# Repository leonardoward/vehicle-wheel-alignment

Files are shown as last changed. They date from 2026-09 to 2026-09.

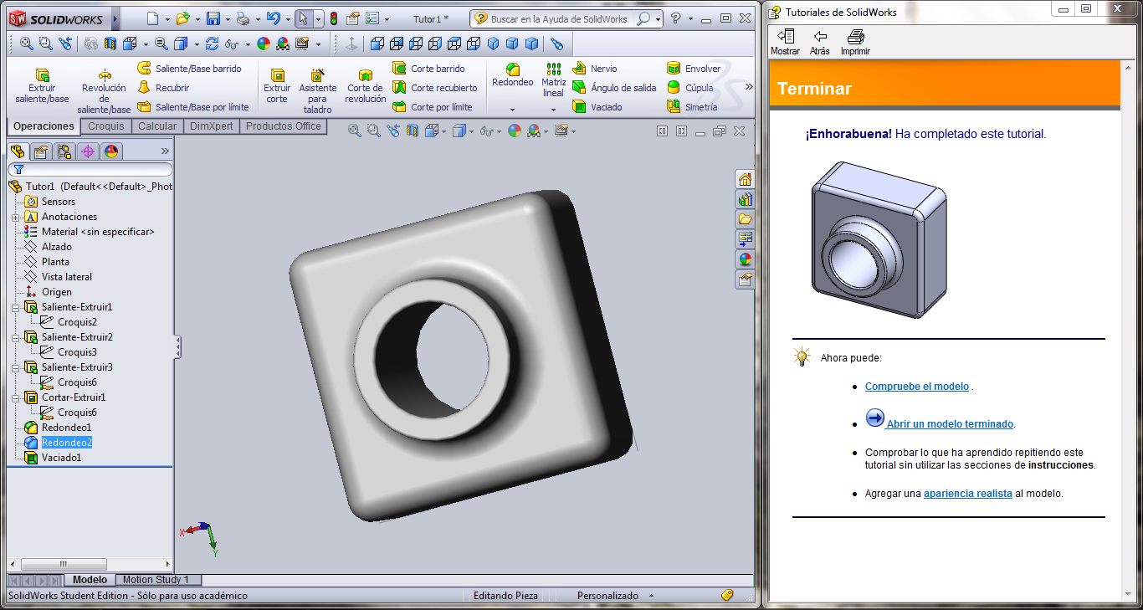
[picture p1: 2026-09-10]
Sistema de Alineación/Tutoriales/Tutorial1a.png

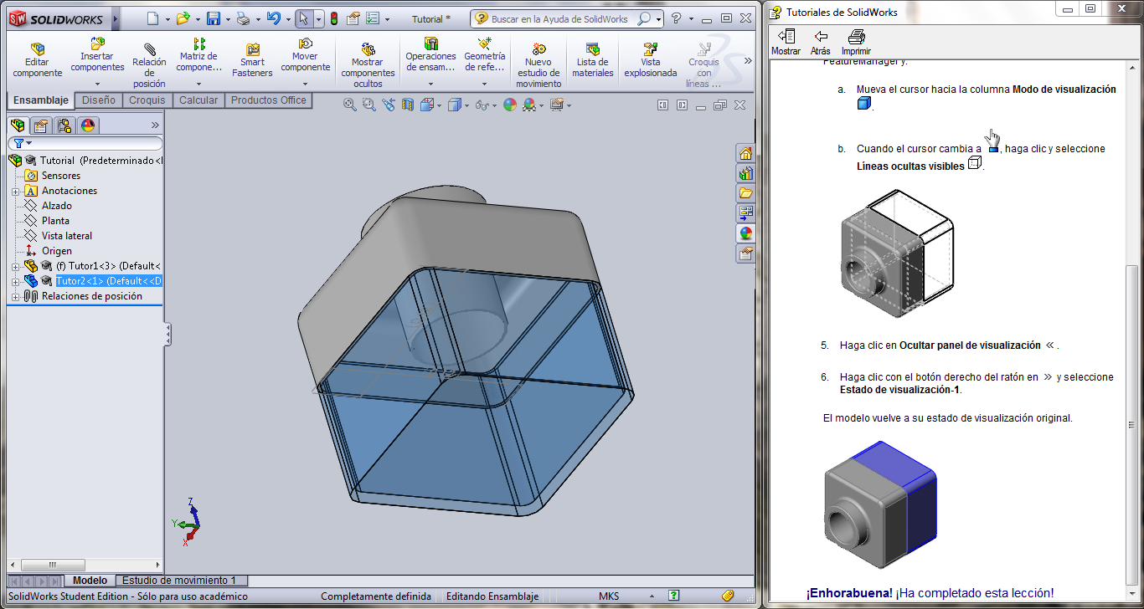
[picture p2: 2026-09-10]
Sistema de Alineación/Tutoriales/Ensamblaje2.png

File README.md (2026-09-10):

# Electronic Wheel Alignment &mdash; Baja SAE USB

An electronic wheel&#8209;alignment system for the **Baja SAE USB** off&#8209;road vehicle
prototypes (Universidad Simón Bolívar). It measures each wheel's **camber** with an
accelerometer and the **toe** (distances between the wheels) with ultrasonic sensors,
and shows the driver / mechanic what to adjust on a small handheld display.

*Leonardo Ward &mdash; Equipo Baja SAE USB (Divisiones de Electrónica y de Suspensión),
Sartenejas, August 2013.*

## Table of Contents

1. [Why](#why)
2. [What It Measures](#what-it-measures)
3. [System Architecture](#system-architecture)
4. [Camber &mdash; the Accelerometer](#camber--the-accelerometer)
5. [Toe &mdash; the Ultrasonic Sensors](#toe--the-ultrasonic-sensors)
6. [Mechanical Coupling](#mechanical-coupling)
7. [Tests](#tests)
8. [Repository Layout](#repository-layout)
9. [License](#license)

## Why

The Baja team aligned its cars **by hand** &mdash; parallel lines chalked on the floor
(or cones joined with string), then a tape measure to set each wheel parallel to them.
There was no way to read the actual **camber** angle or to check that the four wheels
were symmetric. Commercial electronic aligners (IR heads bolted to a bench, a PC doing
the maths) are far too big and expensive for a student team.

The design targets: cost under 3000&nbsp;Bsf, everything inside 50&times;50&times;50&nbsp;cm,
a simple user interface, and a written guide.

## What It Measures

* **Camber** &mdash; the angle of the wheel plane away from vertical.
* **Toe** &mdash; via the horizontal distances between reference points on the four
  wheels. For a symmetric car the paired distances must match: `D1 = D2`, `D3 = D4`,
  `D5 = D6`.

The theory section of the report also covers kingpin inclination, caster, the Ackermann
condition and the Jeantaud steering trapezoid.

## System Architecture

Five modules:

| Module | Radio | Bus | Role |
| --- | ----- | --- | ---- |
| **User interface** | XBee (master) | &mdash; | 16&times;2 LCD, push&#8209;buttons, µC. Shows the angles and a simple wheel diagram telling you which way to adjust. |
| **Wheel 1** | XBee (slave) | I²C (master) | accelerometer + ultrasonic sensors + µC; bridges the wheel bus to the UI over XBee |
| **Wheel 2 / 3 / 4** | &mdash; | I²C (slave) | accelerometer + ultrasonic sensors + µC |

The four wheel modules sit on a single 3&#8209;wire bus on the car &mdash; **Vdd, SDA, SCL**
(I²C, with pull&#8209;ups). Wheel&nbsp;1 is the I²C master and also carries the XBee that
talks wirelessly to the handheld UI module. (A CAN&#8209;bus version was sketched first;
the built system uses XBee&nbsp;+&nbsp;I²C.)

Each wheel module has its own **5&nbsp;V and 3.3&nbsp;V regulators**, and every module has
an ICSP header for programming.

## Camber &mdash; the Accelerometer

An **ADXL335** (±3&nbsp;g, 3&#8209;axis) is mounted parallel to the wheel. With the car
stationary the only acceleration is gravity, so the sensor's X/Y/Z outputs give the
wheel plane's tilt relative to vertical.

At 3.3&nbsp;V supply the ADXL335 sits at 0&nbsp;g = 1.65&nbsp;V with a 330&nbsp;mV/g scale.
Read through a 10&#8209;bit ADC:

```
a [m/s²] = ( reading_mV − 1650 ) / 330 × 9.80665
```

## Toe &mdash; the Ultrasonic Sensors

40&nbsp;kHz ultrasonic emitter/detector pairs on the **inner** face of each tyre (the
wave can't pass through the wheel). Time&#8209;of&#8209;flight &times; the speed of sound gives
the distance to the reference point on another wheel; comparing the symmetric pairs
tells you the toe error. Ultrasonic was chosen over laser: cheaper, smaller, and no
separate receiver structure to mount.

## Mechanical Coupling

SolidWorks parts and assemblies to attach the electronics to the car:

* a clamp (*pinza*) with a torsion spring that grips each tyre;
* an articulated **link&#8209;chain arm** that references a longitudinal axis of the car;
* tube&#8209;axle and end&#8209;cap parts, and the base plates.

## Tests

* **ADXL335** &mdash; bench&#8209;tested in the datasheet's three reference orientations. The
  raw sensor showed a noticeable zero offset and scale error (e.g. ~1.3&nbsp;g read
  where 1&nbsp;g was expected on one axis), so a per&#8209;axis calibration is needed
  before the angle is trustworthy. Results are in
  `Resultados Prueba de Acelerómetros.xlsx`.
* Ultrasonic driver circuits were prototyped in **Multisim** (`*.ms12`).

## Repository Layout

```
README.md
LICENSE                                        MIT
Sistema de Alineación/
  Informe Sistema de Alineación.docx           main report (theory, design, tests)
  Acople mecánico… / Explicación ultrasonido…  supporting docs
  Árbol de Funciones y Tormenta de Ideas CAN…  function tree + early CAN concept
  Pruebas del Acelerómetro… .docx / .xlsx      camber sensor tests
  Componentes… / Primeras Compras… .xlsx       BOM and purchasing
  Receptor.ms12 / Sistema de alineación alterno*.ms12   Multisim schematics
  Acople con eje longitudinal/ , Acople con las Ruedas/  SolidWorks CAD + tutorials
  *.jpg  (module diagrams, hardware photos, the car on the alignment jig)
  datasheets: adxl335, MB1010, SRF004, P113, TL082, UA741, LM137, MAX232, …
```

## License

MIT &mdash; see [`LICENSE`](LICENSE).

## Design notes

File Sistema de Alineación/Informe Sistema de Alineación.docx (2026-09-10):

UNIVERSIDAD SIMÓN BOLÍVAR

EQUIPO BAJA SAE USB

DIVISIÓN DE ELECTRÓNICA

DIVISIÓN DE SUSPENSIÓN

# Portada

ALINEACIÓN ELECTRÓNICA

Por:

Leonardo Jesús Ward Valdez

Sartenejas, Agosto de 2013

# INDICE GENERAL

Pág.

INTRODUCCIÓN………………………………………………………………….. 4

CAPÍTULO 1………………………………………………………………………. 5

MARCO TEÓRICO……………………………………………………………….. 5

  1.1. Ángulo de salida (kin-pin inclination)…………………………………….. 7
  1.2. Ángulo de caída (camber)…………………………………………………. 8
  1.3. Ángulo de inclinación……………………………………………………... 8
  1.4. Ángulo de avance (caster)………………………………………………… 9
  1.5. Convergencia y divergencia de las ruedas (toe-in, toe-out)………………. 10

CAPÍTULO 2……………………………………………………………………... 11

ANTECEDENTES……………..………………………………………………… 11

  1.1. Método manual….………………………………………………………… 11
  1.2. Alineación electrónica…..………………………………………………… 11

CAPÍTULO 3……………………………………………………………………... 13

DESCRIPCIÓN DEL SISTEMA………………………………………………… 13

  2.1. Ajuste del Ángulo total de inclinación (Camber)………………………..... 13
  2.2. Distancia entre las ruedas…………………………………………………. 13
  2.3. Acople a los cauchos…………………………………………………….... 14
  2.4. Interface…………………………………………………………………… 14
  2.5. Funcionamiento del sistema………………………………………………. 15
    2.5.1. Módulo de interface con el usuario………………………………… 16
      2.5.1.1. LCD 16x2…………………………………………………… 16
      2.5.1.2. Módulo XBEE………………………………………………. 17
      2.5.1.3. Regulador de Voltaje a 5V………………………………….. 17
      2.5.1.4. Conector para programación del microcontrolador…………. 17
      2.5.1.5. Pulsadores…………………………………………………… 18
      2.5.1.6. Microcontrolador……………………………………………. 18
    2.5.2. Módulos de las ruedas…………………………………………….. 19
      2.5.2.1. Reguladores de Voltaje (a 5V y a 3.3V)…………………... 19
      2.5.2.2. Módulo XBEE…………………………………………….. 19
      2.5.2.3. Acelerómetros……………………………………………… 20
      2.5.2.4. Conector para programación del microcontrolador……….. 20
      2.5.2.5. Microcontrolador………………………………………….. 20

CAPÍTULO 4……………………………………………………………………... 22

PRUEBAS………………………………………………………………………... 22

CONCLUSIONES…………………………………………………………………... 25

REFERENCIAS…………………………………………………………………….. 26

APÉNDICE A………………………………………………………………………. 27

Datasheet de ADXL335 (Acelerómetro)………………………………………. 27

Datasheet del Sensor Ultrasonico 40 kHz……………………………………... 41

# INTRODUCCIÓN

El presente proyecto trata de la elaboración de un sistema de alineación electrónica, para ser utilizado en los prototipos de Baja SAE de la Universidad Simón Bolívar.

Problemas:

- Falta de simetría para en el vehículo
- Falta de sistema para medición del ángulo de inclinación del caucho y su relación con los otros.

Objetivos:

- Obtener simetría en el vehículo.
- Realizar un sistema para medición del ángulo de inclinación del caucho y su relación con los otros.

Restricciones:

- Costos menor a 3000 Bsf
- Volumen menor a 50x50x50 cm^3
- Fácil interfaz con el usuario
- Guía o manual

# CAPÍTULO 1

# MARCO TEÓRICO

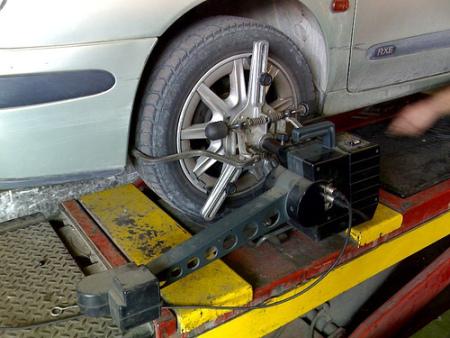
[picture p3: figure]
Alineado de ruedas. Flickr (Pedro)

Cuando el conductor toma el volante entre sus manos, utiliza el sistema de la dirección para trazar el recorrido que debe seguir su vehículo. A la dirección se le atribuyen varias características: seguridad, suavidad, precisión e irreversibilidad. Si el sistema funciona adecuadamente, esas características ayudarán al conductor a orientar el vehículo según sus necesidades.

La seguridad del funcionamiento del sistema viene determinada por la fiabilidad de los mecanismos que lo componen. La suavidad, necesaria para conseguir cómodamente respuestas ágiles, viene dada por la facilidad de manejo que nos dé la propia dirección. La precisión necesaria para el buen trazado de las rutas designadas por el conductor tiene su base en la exactitud de los mecanismos que componen el sistema. Finalmente, la irreversibilidad consiste en la capacidad que debe tener la dirección de funcionar al margen de los factores externos que podrían repercutir sobre el volante, como un firme en mal estado.

Quizá sea bueno echarle un ojo por encima a la cantidad de medidas calculadas que se realizan para que la dirección funcione de forma correcta. Será una forma de hacernos una idea sobre lo preciso que es y debe ser este sistema.

Para que un vehículo recorra una curva es necesario que se cumpla una condición geométrica, conocida como principio de Ackerman y que viene a decir que cuando un vehículo gira los ejes de todas las ruedas deben concurrir en un mismo punto, que llamamos centro instantáneo de giro.

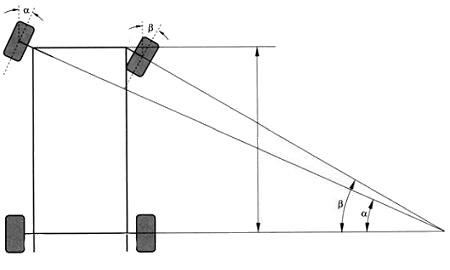
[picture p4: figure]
Principio de Ackerman. SCT

Tal como se aprecia en el dibujo de arriba, la rueda que queda en el interior de la curva se cierra más que la rueda que gira por el exterior. Dicho de otra forma, en una curva, cada una de las ruedas directrices se cierra de forma diferente. El ángulo que en una curva forma la rueda exterior con el eje trasero (rotulado como α) es menor que el ángulo que forma la rueda interior con el eje trasero (identificado como ß). Si esto no se respetara, las ruedas se arrastrarían transversalmente, y acabarían destrozándose. Para conseguir estos ángulos, se le da a una parte del eje de las ruedas directrices, las llamadas bieletas de mando, una cierta inclinación. Cuando el vehículo se encuentra en línea recta, la prolongación de esas bieletas llega hasta el centro del eje trasero del vehículo. Es lo que se denomina trapecio de Jeantaud, marcado en rosa en este otro dibujo.

Y para que todo el sistema funcione adecuadamente, cada una de las ruedas directrices debe seguir una serie de condiciones geométricas, que llamamos cotas de dirección y que veremos seguidamente de forma abreviada:

## 1.1 Ángulo de salida (kin-pin inclination)

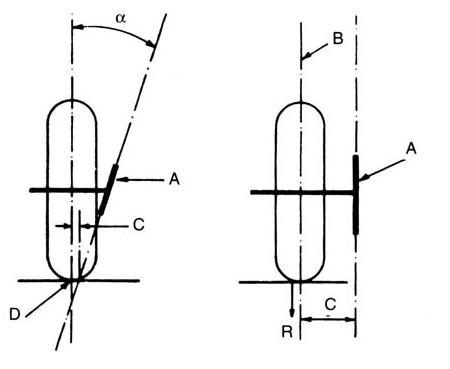
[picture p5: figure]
Ángulo de salida. SCT

Es el ángulo que forma la prolongación del eje del pivote, sobre el que gira la rueda para orientarse, con la prolongación del eje vertical que pasa por el centro de apoyo de la rueda. En el dibujo aparece identificado como α. Suele estar comprendido entre 5 y 10º, siendo lo habitual entre 6 y 7º. A la hora de girar las ruedas, es necesario vencer el par resistente que resulta de multiplicar R por C. Al inclinar el pivote, se consigue que la distancia C sea menor, por lo que se necesitará un esfuerzo también menor para conseguir el giro deseado. Vale la pena tener en cuenta que unos neumáticos mal inflados repercuten en la distancia C, con lo que el esfuerzo necesario para girar las ruedas puede verse incrementado.

## 1.2 Ángulo de caída (camber)

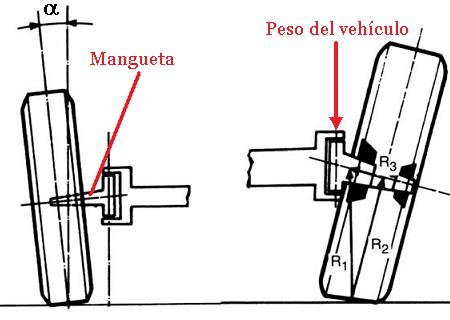
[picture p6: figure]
Ángulo de caída. SCT

Es el ángulo que forma la prolongación del eje de simetría de la rueda con el vertical que pasa por el centro de apoyo de la rueda. En el dibujo aparece identificado como α. Este ángulo se consigue dando al eje de la mangueta una cierta inclinación con respecto al plano horizontal. Así se desplaza el peso del vehículo que gravita sobre este eje hacia el interior de la mangueta y se disminuye el empuje lateral de los cojinetes sobre los que se apoya la rueda. Suele estar comprendido entre treinta minutos y un grado.

## 1.3 Ángulo de inclinación

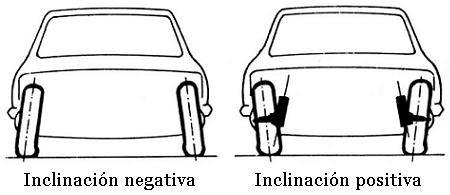
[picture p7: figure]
Ángulo de inclinación. SCT

Es la suma de los ángulos de salida y caída, y determina la inclinación que toma la rueda sobre el terreno respecto de su parte superior. Un ángulo de inclinación adecuado redundará en un buen agarre del neumático sobre la calzada. Un ángulo excesivamente negativo o positivo dará pie a deformaciones del neumático, aumento de la temperatura interior y fatiga de los flancos, hasta llegar a la rotura de las bandas que componen la carcasa.

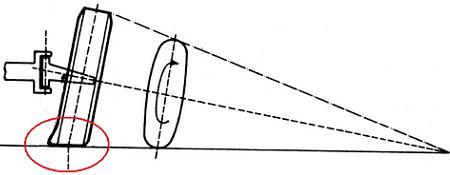
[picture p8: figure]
Exceso en el ángulo de inclinación. SCT

## 1.4 Ángulo de avance (caster)

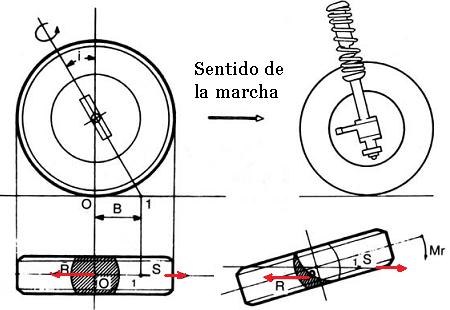
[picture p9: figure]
Ángulo de avance. SCT

Es el ángulo que forma la prolongación del pivote con el eje vertical que pasa por el centro de la rueda en el sentido de la marcha. La idea es que la prolongación del eje del pivote toque el suelo por delante del punto de contacto de la rueda con el terreno. De esta forma, aparece un efecto remolque en las ruedas, ya que las fuerzas que intervienen (marcadas en rojo en el dibujo) tiran desde puntos de aplicación diferentes cuando la rueda se encuentra en pleno giro. Esto ayuda a poner rectas las ruedas cuando acabamos de girar y cuando encontramos irregularidades en el terreno.

El ángulo de avance suele estar comprendido entre 0 y 4º para vehículos de tracción y de 6 a 12º para vehículos de propulsión para contrarrestar la inestabilidad que experimenta el eje delantero cuando es empujado desde el eje trasero del vehículo.

## 1.5 Convergencia y divergencia de las ruedas (toe-in, toe-out)

Al conjugar las diferentes cotas de la dirección, podemos encontrarnos con que las ruedas delanteras no son completamente paralelas, sino que convergen o divergen dependiendo de las necesidades dinámicas del vehículo en materia de suspensiones, fuerzas del motor sobre las ruedas y resistencia al avance.

Por poner un ejemplo, un turismo de propulsión, por efecto del empuje del eje trasero, tendrá tendencia a que sus ruedas delanteras diverjan. Por ese motivo, el fabricante buscará unos ángulos que lleven a las ruedas delanteras hacia la convergencia. La idea es que cuando el vehículo se mueva las ruedas vayan tan paralelas como sea posible para evitar la inestabilidad de la dirección y asegurar la estabilidad del vehículo. Una convergencia o divergencia excesiva se manifestaría por la propia ingobernabilidad del vehículo y por el desgaste irregular en las bandas de rodadura de los neumáticos.

# CAPÍTULO 2

# ANTECEDENTES

## 1.1 Método manual

Este es un método muy intuitivo que fue utilizado por mucho tiempo por los dueños de vehículos antes de la llega de la alineación electrónica. Consiste en el uso de unos puntos de referencia que se sabe son paralelos entre sí, para ajustar las ruedas en función a dichos puntos, y de esta forma lograr que las ruedas estén paralelas entre sí.

Este método se ha utilizado en el equipo Baja SAE USB durante mucho tiempo, ya sea mediante la implementación de líneas paralelas entre sí, dibujadas en el suelo, o mediante el uso de conos unidos por cuerdas, y dispuestos de forma que ellas se encuentran paralelas entre sí. Y por último se procede a ajustar las ruedas para que estén paralelas a dichas líneas o cuerdas utilizando una cinta métrica.

## 1.2 Alineación electrónica

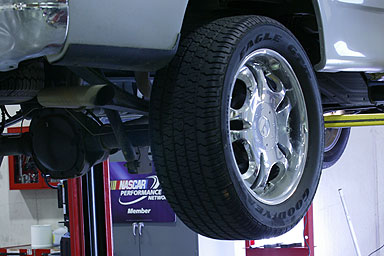
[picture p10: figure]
alineacion y balanceo

Este sistema es comúnmente empleado en los talleres que ofrecen la alineación del vehículo, el sistema consiste en montar el carro en un gran banco de prueba, y colocarle un dispositivo muy voluminoso y costoso (que por lo general está anclado al banco de prueba) a cada rueda, dichos dispositivos tienen sensores infrarrojos y se comunican a una computadora que realiza los cálculos, obteniendo de esta forma la información necesaria para la alineación del vehículo.

Como ejemplo, se muestra a continuación el Geoligner DSP 6S, un equipamiento desarrollado y producido en Brasil, destinado a alinear vehículos. Este dispositivo efectúa el alineamiento con un total por 4 cabezas medidoras y 6 sensores infrarrojos.

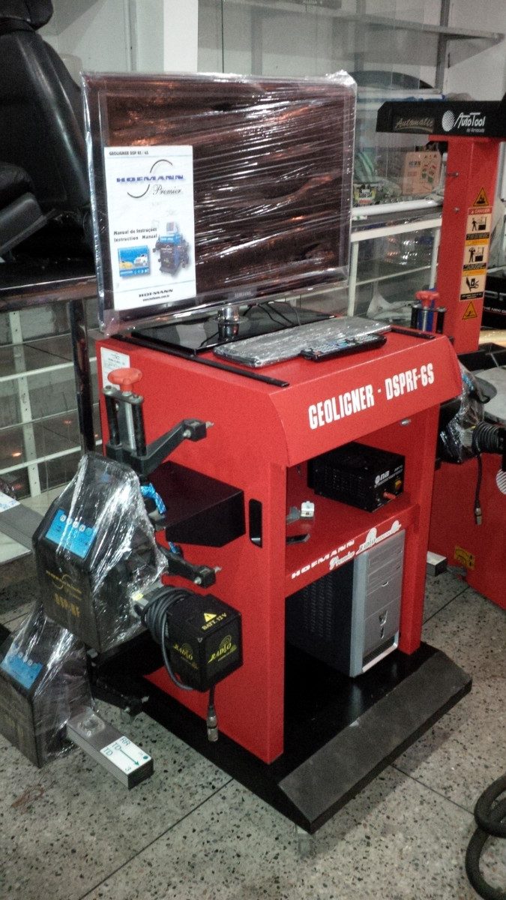
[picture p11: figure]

# CAPÍTULO 3

# DESCRIPCIÓN DEL SISTEMA

## 2.1 Ajuste del Ángulo de inclinación (Camber)

Para corregir el ángulo de inclinación con respecto al suelo se utilizan acelerómetros. Dichos dispositivos determinan las aceleraciones presentes en los 3 ejes (en el caso del modelo ADXL335). Una de las aceleraciones presentes en el sistema es la gravedad, por lo tanto se coloca el sensor paralelo al caucho (como se muestra en la imagen), ocasionando que se vean reflejadas las componentes de la gravedad en los ejes; y dicha información se utilizará para calcular el ángulo de inclinación.

Para realizar el cálculo del camber de la rueda, se utilizará el acelerómetro ADXL335:

Este componente nos permite medir las aceleraciones en los 3 ejes y consta de 5 pines importantes:

-VCC= Alimentación (de 1.8 a 3.6 voltios)

-GND= Tierra

-X = Punto de lectura de aceleraciones del eje X

-Y = Punto de lectura de aceleraciones del eje Y

-Z = Punto de lectura de aceleraciones del eje Z

-ST= Self Test (no conectamos este pin)

Para poder medir un ángulo con respecto a la vertical, hacemos uso de la medición de la aceleración de la gravedad.

## 2.2 Distancia entre las ruedas

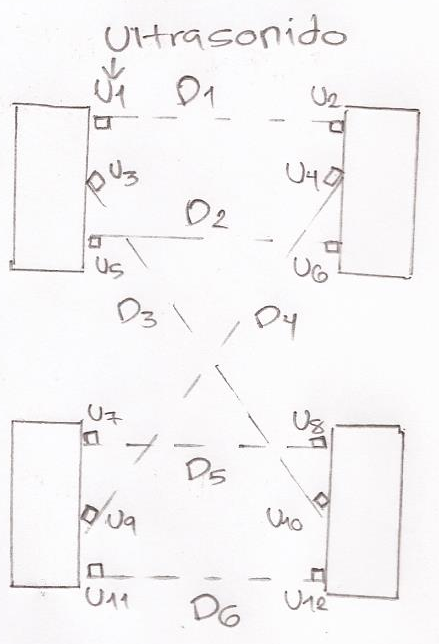
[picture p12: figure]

En la imagen anterior se observan las distancias que permiten determinar la alineación del el carro, se debe cumplir que D1=D2, D3=D4, D5=D6, y estas mediciones se llevarán a cabo utilizando sensores de ultrasonido, estos sensores constan de un emisor y un detector, el emisor genera una onda, y el detector la recibe, si se mide el tiempo en el que ocurre este hecho, junto con la velocidad del sonido en el aire (valor que es conocido) se obtienen dichas distancias. Se decidió utilizar los ultrasonido debido al bajo costa y al poco espacio que ocupan los sensores, a diferencia de los sensores que miden distancia por laser, y tiene el inconveniente de que necesitan una estructura para el receptor de la señal del laser, lo que lo hace una opción más costosa y voluminosa.

## 2.3 Acople a los cauchos

Adicionalmente es necesario unir estos dispositivos a los cauchos, la imagen anterior muestra una representación de los cauchos desde distintos ángulos, en la parte lateral interna se encuentran los sensores de ultrasonido, por ejemplo U1 y U2 permiten medir la distancia D1, pero las ondas no pueden atravesar los objetos por lo que los sensores se deben colocar en la parte lateral interna, el acelerómetro se puede colocar en la parte lateral interna o externa del caucho.

## 2.4 Interface

Por último, la relación con el usuario es un aspecto muy importante, el sistema contará con una pantalla de cristal líquido, esta le transmitirá la información necesaria para realizar los ajustes en el carro y así lograr una correcta alineación. Además de informar sobre los ángulos, dicha pantalla mostrará un esquema muy básico de las ruedas que mostrará de forma muy intuitiva las acciones a tomar en el proceso de alineación.

## 2.5 Funcionamiento del Sistema

El sistema consta de 5 módulos:

El primero se encarga de la interface con el usuario, posee una tarjeta te comunicación inalámbrica xbee que se comunicará una de las tarjetas que se encuentra en alguno de los cauchos del carro.

Los otros 4 modulos se encuentran en cada uno de los cauchos, y se comunican entre sí por I2C, y con el módulo de interface con el usuario a través de un módulo de comunicación inalámbrica xbee.

### 2.5.1 Módulo de interface con el usuario

Esquemático:

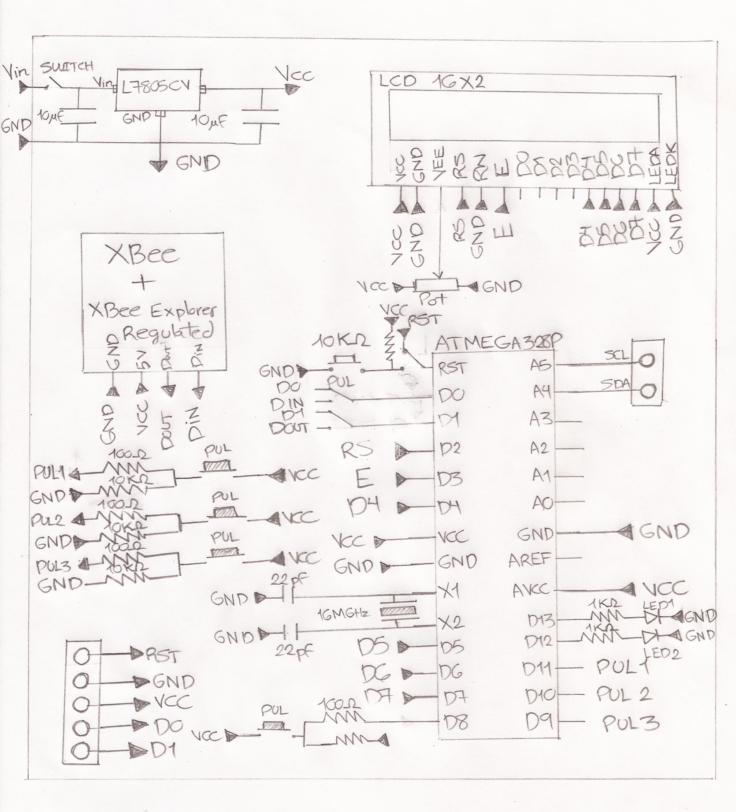
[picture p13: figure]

Podemos dividirlo en 6 partes:

#### 2.5.1.1 LCD 16X2

#### 2.5.1.2 Módulo XBEE

#### 2.5.1.3 Regulador de voltaje a 5V

#### 2.5.1.4 Conector para programación del microcontrolador

#### 2.5.1.5 Pulsadores:

#### 2.5.1.6 Microcontrolador ATMEGA328P:

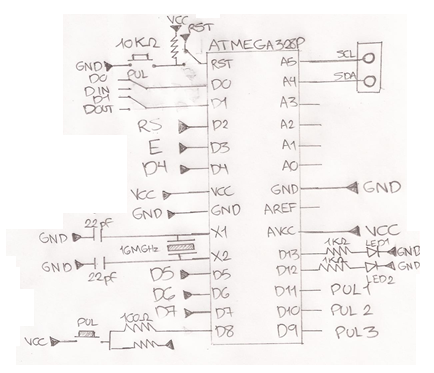
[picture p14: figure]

Este se maneja los 4 pulsadores, el LCD 16X2, y el módulo XBEE, además se puede comunicar utilizando el protocolo de I2C (SDA y SCL)

### 2.5.2 Módulos de las ruedas

Podemos dividirlo en 5 partes:

#### 2.5.2.1 Reguladores de voltaje (a 5V y a 3.3V)

#### 2.5.2.2 Módulo XBEE

#### 2.5.2.3 Acelerómetro ADXL335

#### 2.5.2.4 Conector para programación del microcontrolador

#### 2.5.2.5 Microcontrolador ATMEGA328P:

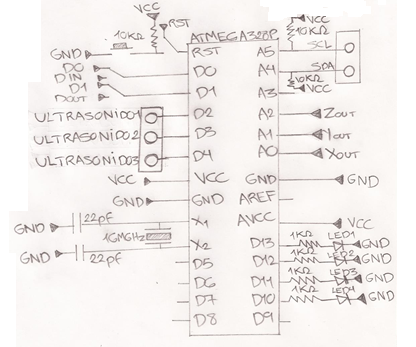
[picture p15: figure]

El microcontrolador se encarga de manejar 3 sensores de ultrasonido, el módulo de comunicación inalámbrica, 3 leds, y se comunica por medio de I2C con los otros 3 módulos iguales a si mismo que se encuentran en las otras 3 ruedas.

# CAPÍTULO 4

# PRUEBAS

Se realizaron pruebas con el acelerómetro ADXL335 para comprobar su respuesta al medir la aceleración de la gravedad en cada uno de sus ejes, lo que permitirá obtener el camber de cada rueda.

Montaje del circuito:

La salida de cada uno de los pines relacionados a cada eje ADXL335 tiene un voltaje proporcional a la aceleración medida, por lo que los conectamos a los pines A0,A1 y A2 del Arduino, ya que el microcontrolador posee ADC (conversor analógico-digital) en los pines que están conectados a esos puertos de la tarjeta por lo que podemos medir las variaciones del voltaje del ADXL335.

Además conectamos el puerto de 3.3V del Arduino a VCC del ADXL335, conectamos las tierras de los dispositivos a la tierra de la batería y el positivo a de la batería lo conectamos al puerto Vin del Arduino que está conectado a un regulador de voltaje que da los 5 voltios que necesita el microcontrolador y a otro que da los 3.3v que necesita el ADXL335 (los reguladores se encuentran en el Arduino). El montaje se muestra en las siguientes figuras.

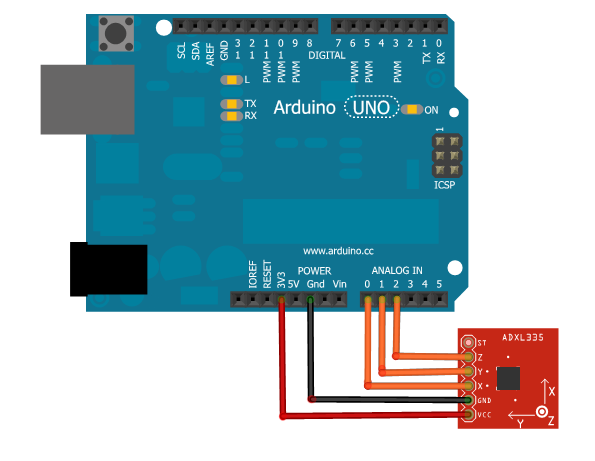
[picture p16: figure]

Diagrama del montaje para las pruebas del ADXL335

El acelerómetro tiene un rango de desde -3g hasta 3g, situando el 0g en la mitad del voltaje de alimentación, es decir, si alimentamos el circuito con 3.3v entonces encontraremos 0g en 1,65 voltios. Además la escala del sensor también varía proporcionalmente con el voltaje de alimentación, si alimentamos el circuito con 3.3v el factor que define la escala es 330mV/g.Para probar el acelerómetro colocamos el sensor en distintas posiciones de modo que registre la aceleración de la gravedad (1g) en un eje distinto en cada oportunidad. Para determinar la posición del sensor nos guiamos por las siguientes imágenes sacadas del Datasheet del ADXL335. Del sensor medimos un voltaje, que el ADC del microcontrolador transforma en 10 bits, por lo que el obtenemos una lectura entre 0 y 1023.

Para obtener la lectura de la aceleración en m/s² utilizamos la siguiente ecuación:

En la ecuación la Lectura es la medida que obtiene el microcontrolador, que convertimos de un número de 10 bits en decimal (valor del voltaje en mV), luego le restamos el voltaje que tiene cuando ninguna aceleración actúa sobre él, (Voltaje0G=VoltajeAlimentación(mV)/2=1650mV), y lo dividimos entre el factor que determina la escala (VoltajeAlimentación(mV)/10=330mV) y lo multiplicamos con el valor de la gravedad G=9.80665m/s².

En las pruebas colocamos el sensor en las siguientes posiciones que nos permitirán medir el valor de la gravedad en los distintos ejes:

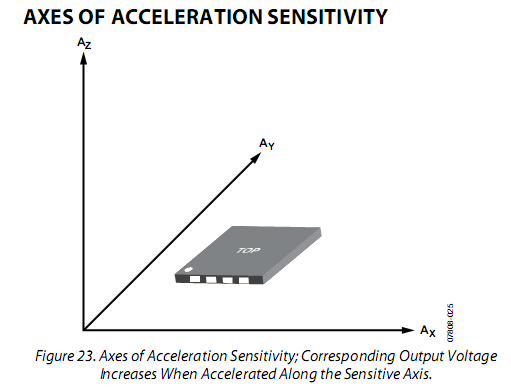
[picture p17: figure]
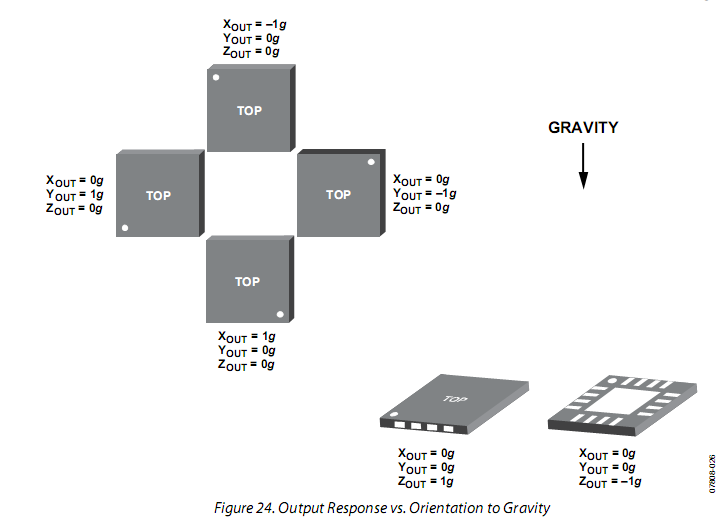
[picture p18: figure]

Resultados:

Probamos 3 posiciones, que se muestran a continuación:

| Posición 1
| Resultados Ideales | | Resultados Reales
Eje | Aceleración (G) | Aceleración (m/s²) | Voltaje (mV) | Aceleración (G) | Aceleración (m/s²)
X | 0 | 0 | 1739,98 | 0,27267 | 2,67395
Y | 0 | 0 | 1661,78 | 0,03570 | 0,35007
Z | 1 | 9,80665 | 2082,11 | 1,30942 | 12,84107

| Posición 2
| Resultados Ideales | | Resultados Reales
Eje | Aceleración (G) | Aceleración (m/s²) | Voltaje (mV) | Aceleración (G) | Aceleración (m/s²)
X | 0 | 0 | 1744,87 | 0,28748 | 2,81926
Y | 1 | 9,80665 | 2038,12 | 1,17612 | 11,53381
Z | 0 | 0 | 1739,98 | 0,27267 | 2,67395

| Posición 3
| Resultados Ideales | | Resultados Reales
Eje | Aceleración (G) | Aceleración (m/s²) | Voltaje (mV) | Aceleración (G) | Aceleración (m/s²)
X | 1 | 9,80665 | 2077,22 | 1,29461 | 12,69575
Y | 0 | 0 | 1691,1 | 0,12455 | 1,22137
Z | 0 | 0 | 1769,31 | 0,36155 | 3,54555

# CONCLUSIONES

Se han obtenido los resultados esperados en las pruebas con el acelerómetro, pero es recomendable ajustar las mediciones para obtener valores más exactos. Además se deberán coordinar los sensores de ultrasonido para que no se hagan interferencia entre ellos.

# REFERENCIAS

http://bimg1.mlstatic.com/alineadora-hofmann-geoligner-dsprf6-monitor-led-32_MLV-F-4331512675_052013.jpg

http://www.analog.com/static/imported-files/data_sheets/ADXL335.pdf

http://www.circulaseguro.com/la-importancia-del-alineado-de-las-ruedas/

http://www.electronicamagnabit.com/tienda/attachment.php?id_attachment=12

http://www.marcadecoche.com/alineacion-y-balanceo.html

http://www.sprintdata.com.py/productos.php?id=9&art=22

https://www.sparkfun.com/products/11373

http://communityofrobots.com/tutorial/kawal/xbee-and-arduino

www.ikkaro.com/comunicacion-i2c-arcuino

# APÉNDICE A

## Datasheet de ADXL335 (Acelerómetro)

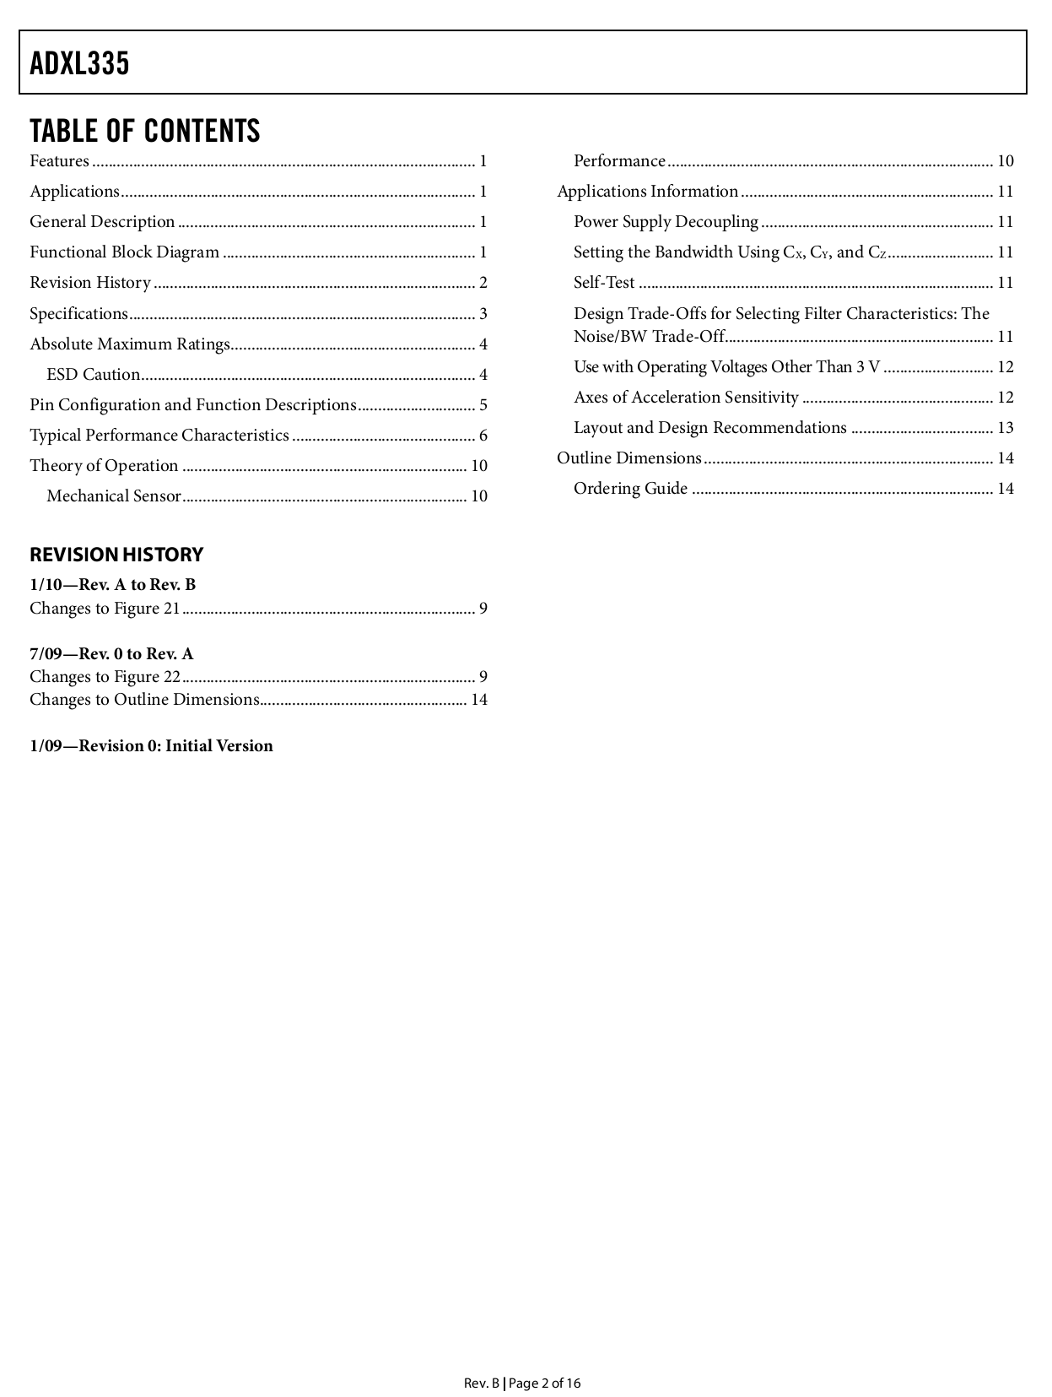
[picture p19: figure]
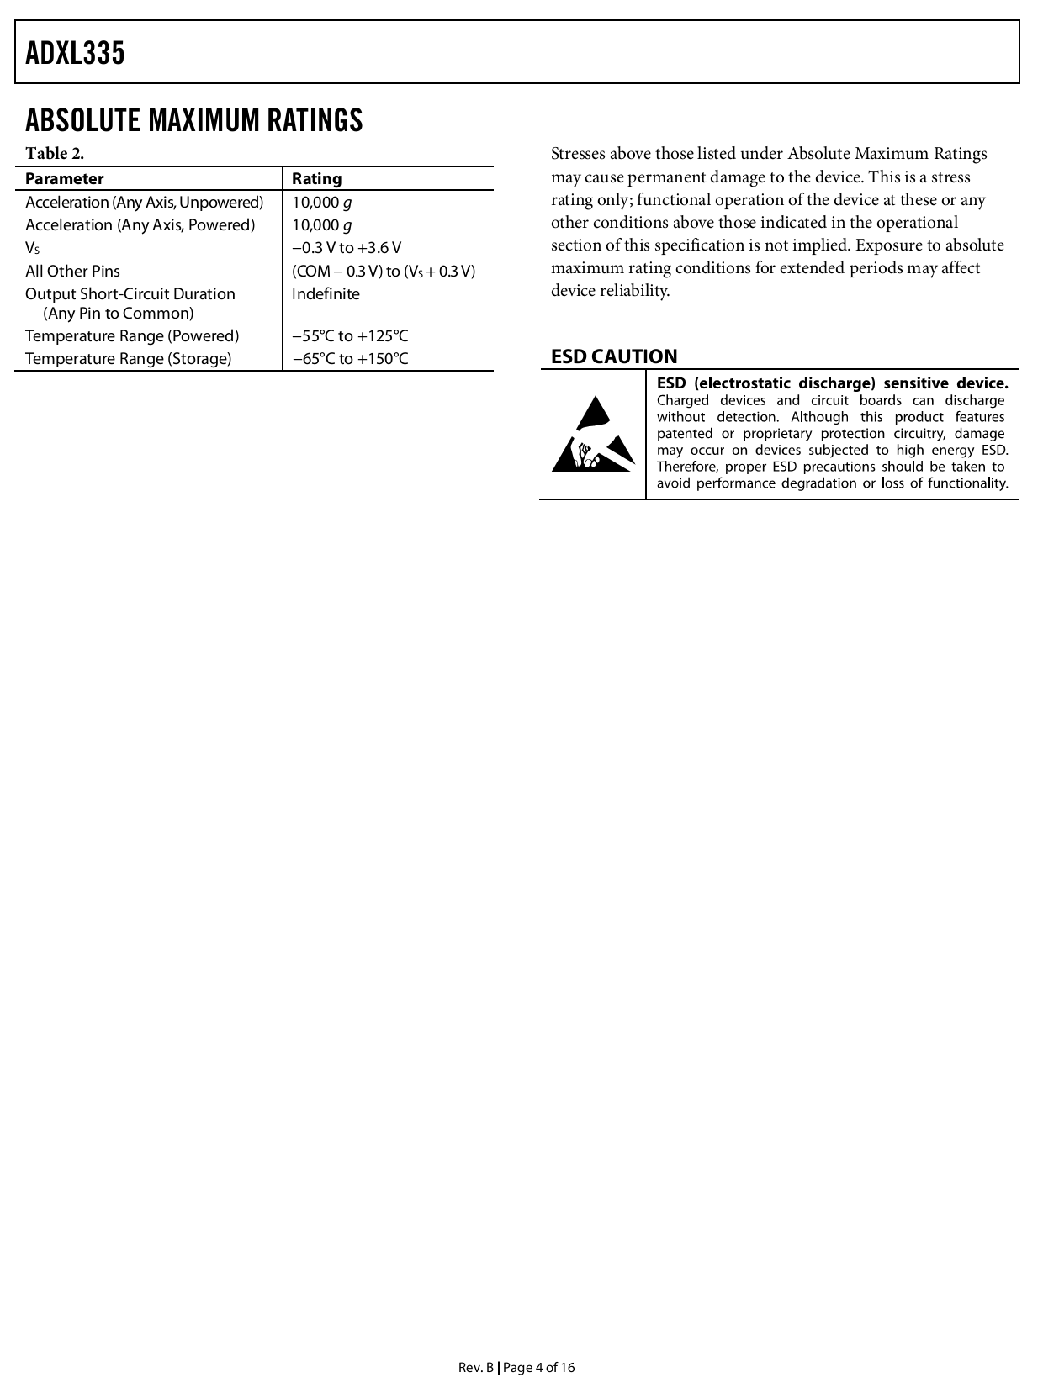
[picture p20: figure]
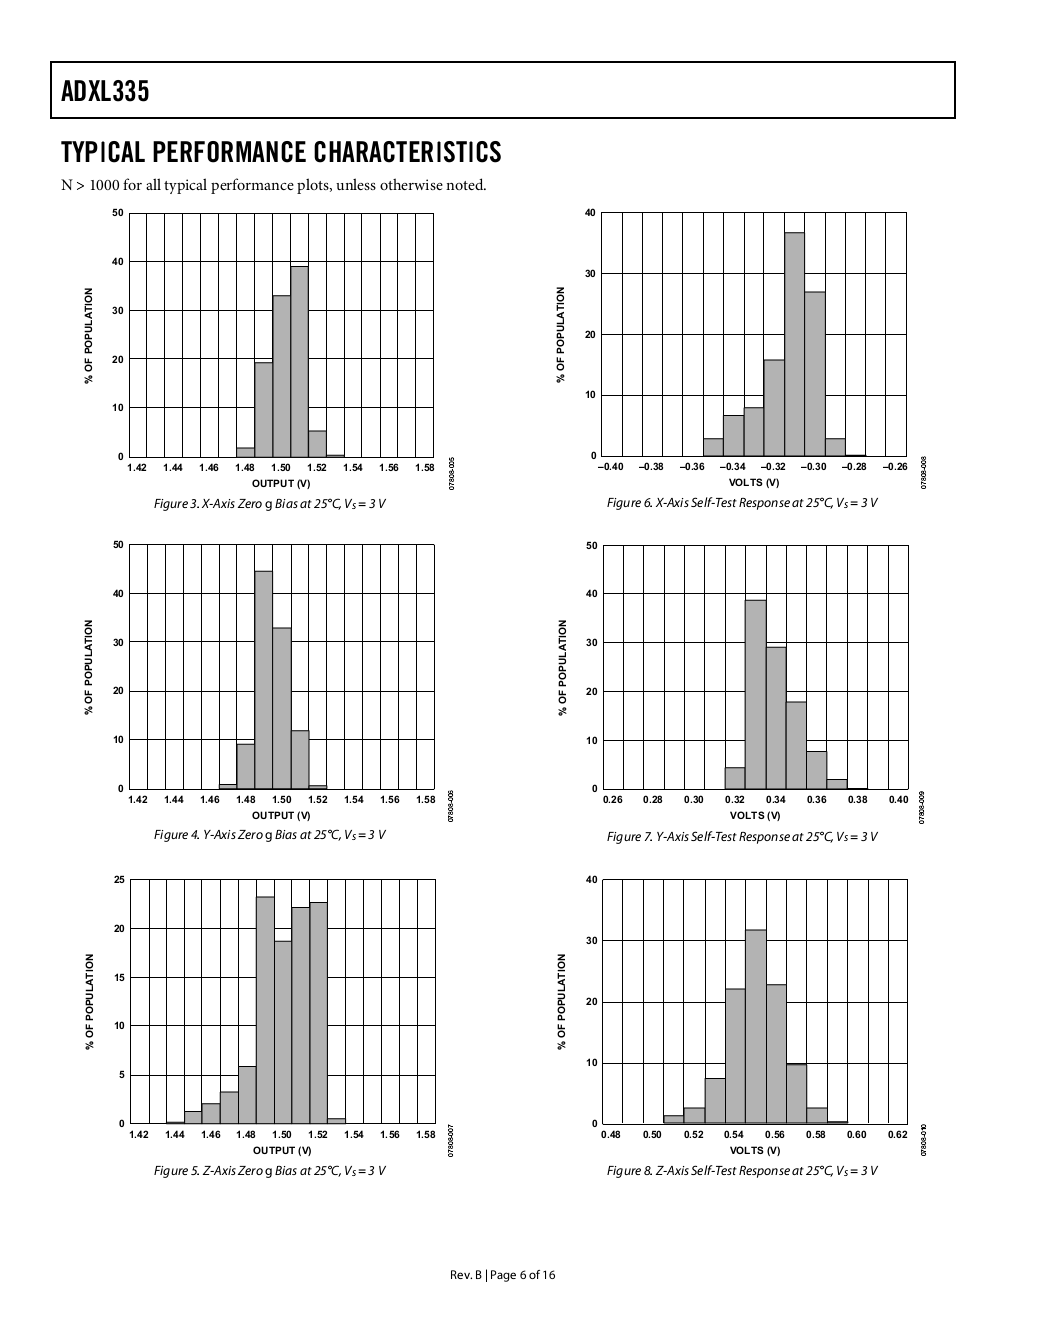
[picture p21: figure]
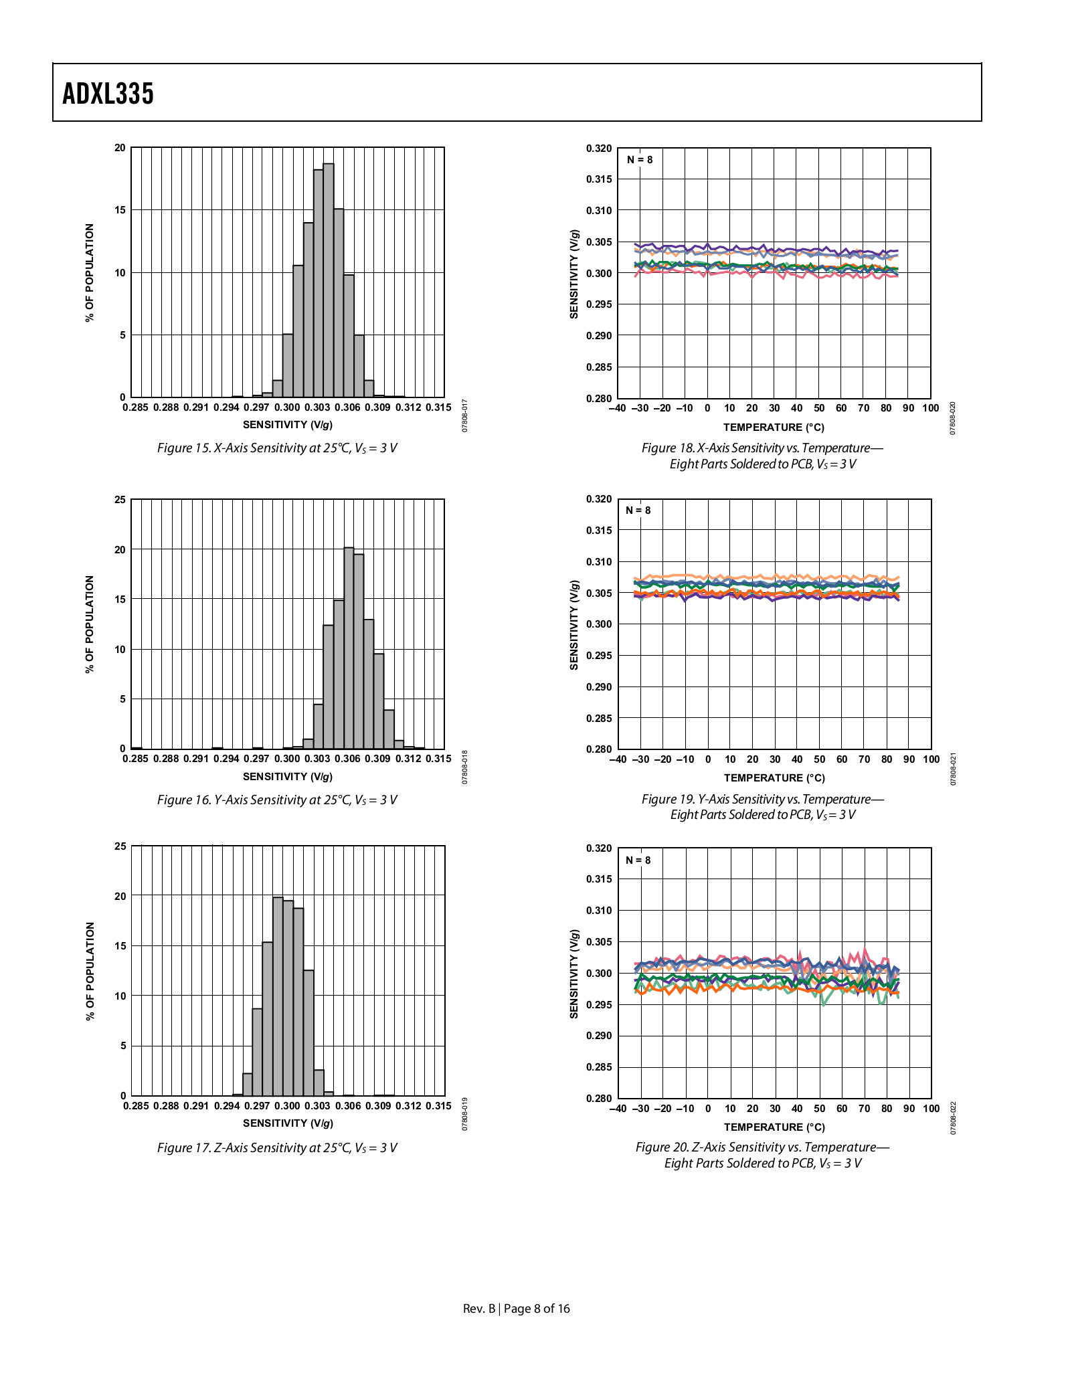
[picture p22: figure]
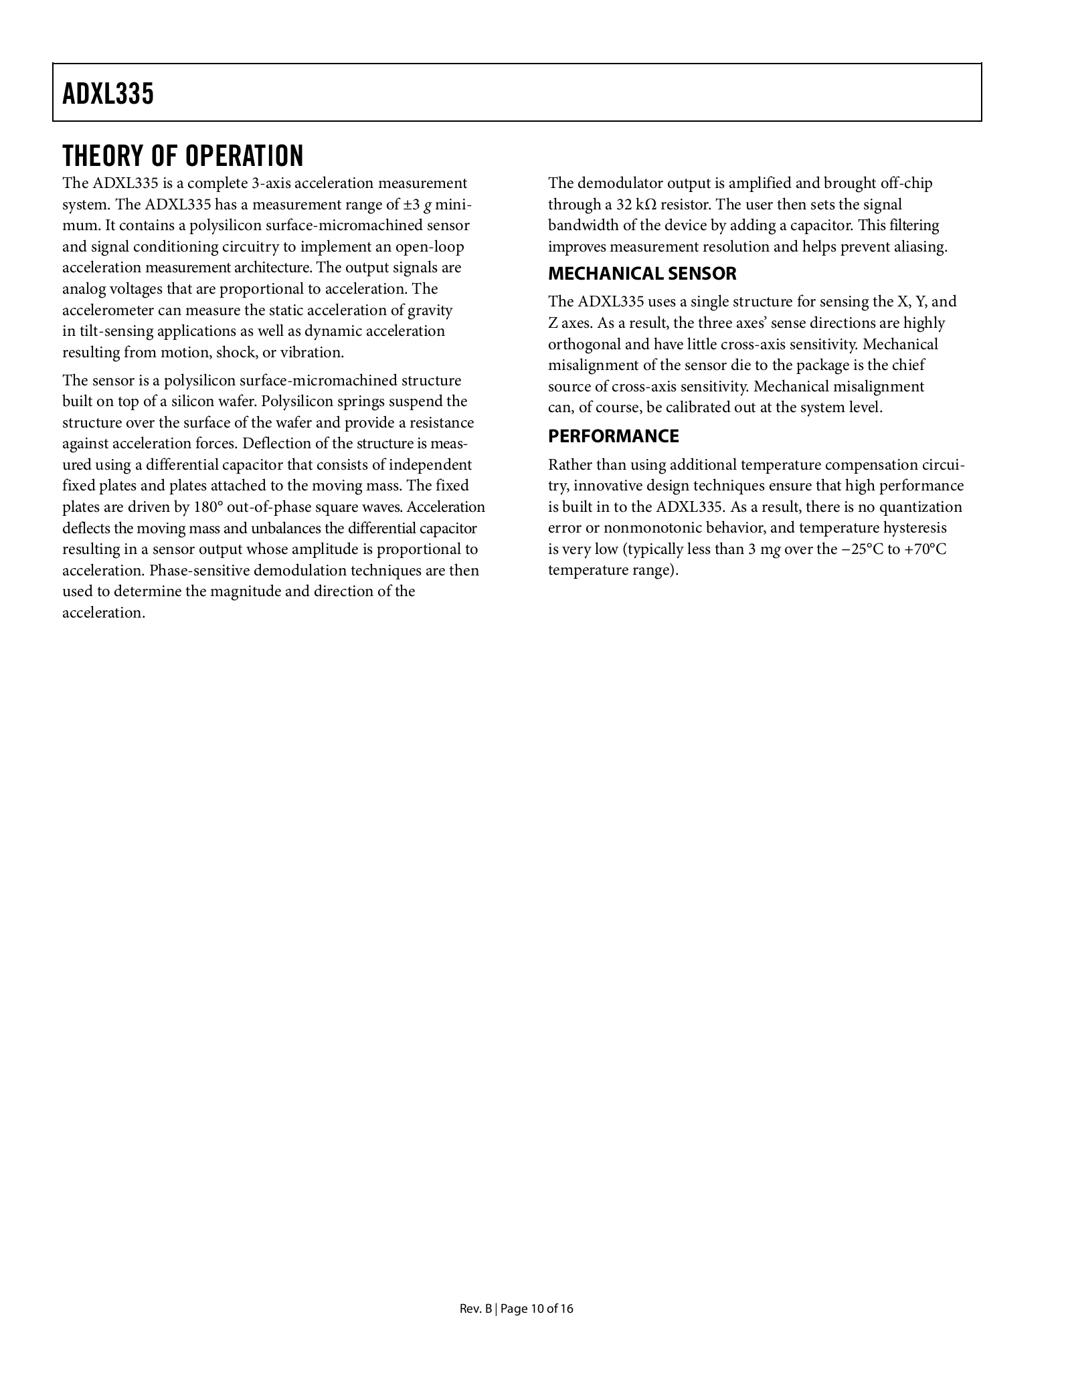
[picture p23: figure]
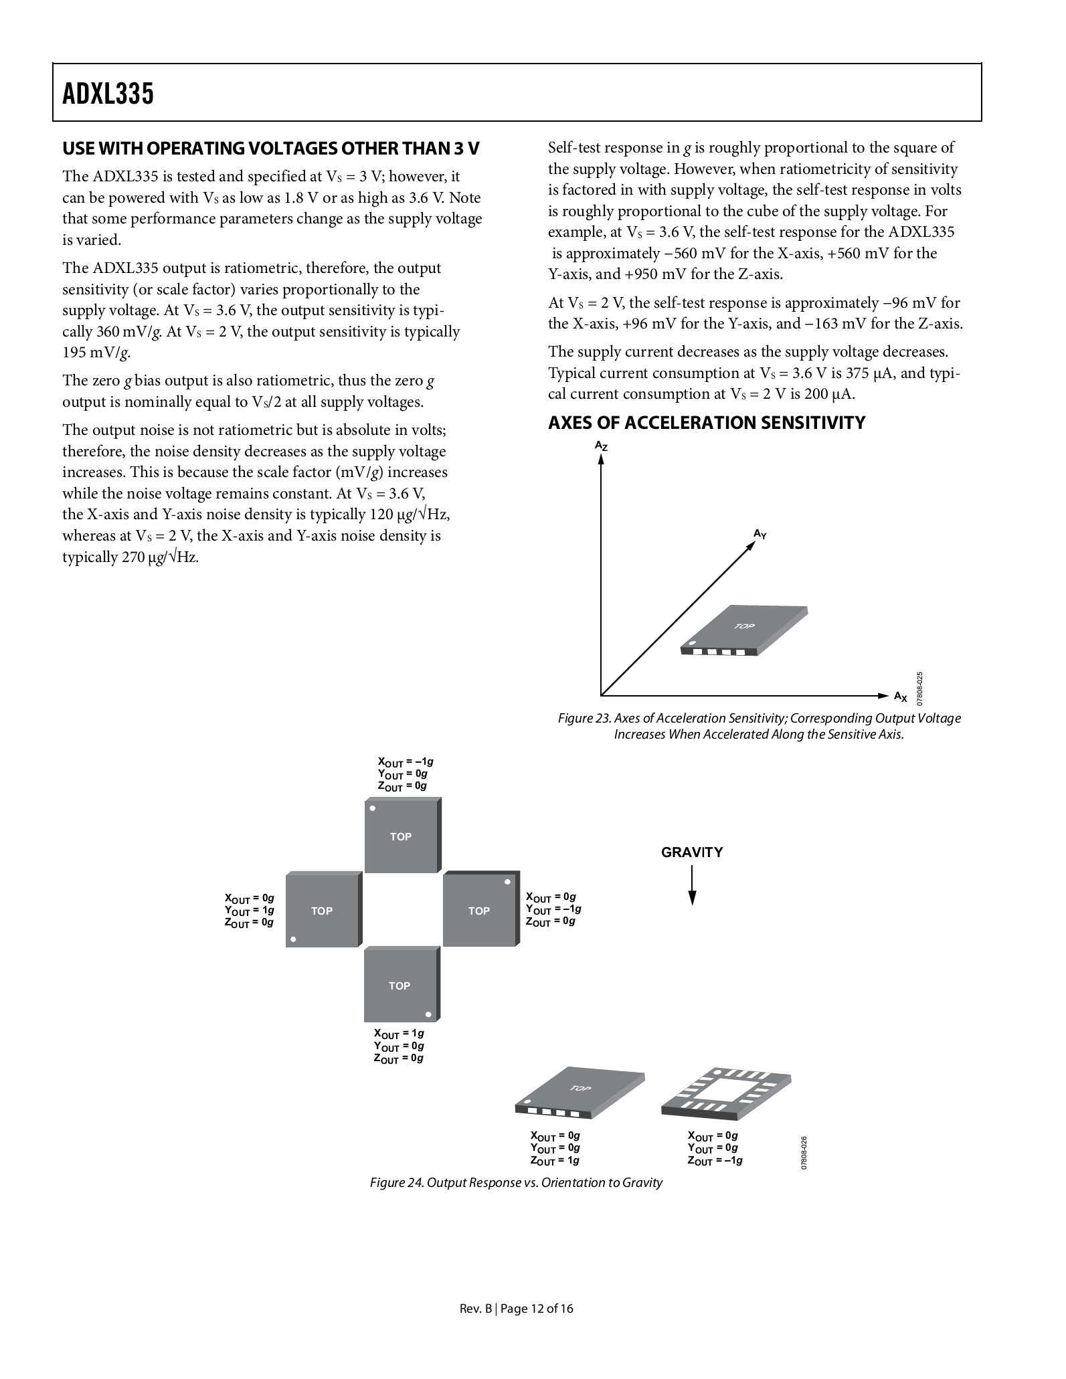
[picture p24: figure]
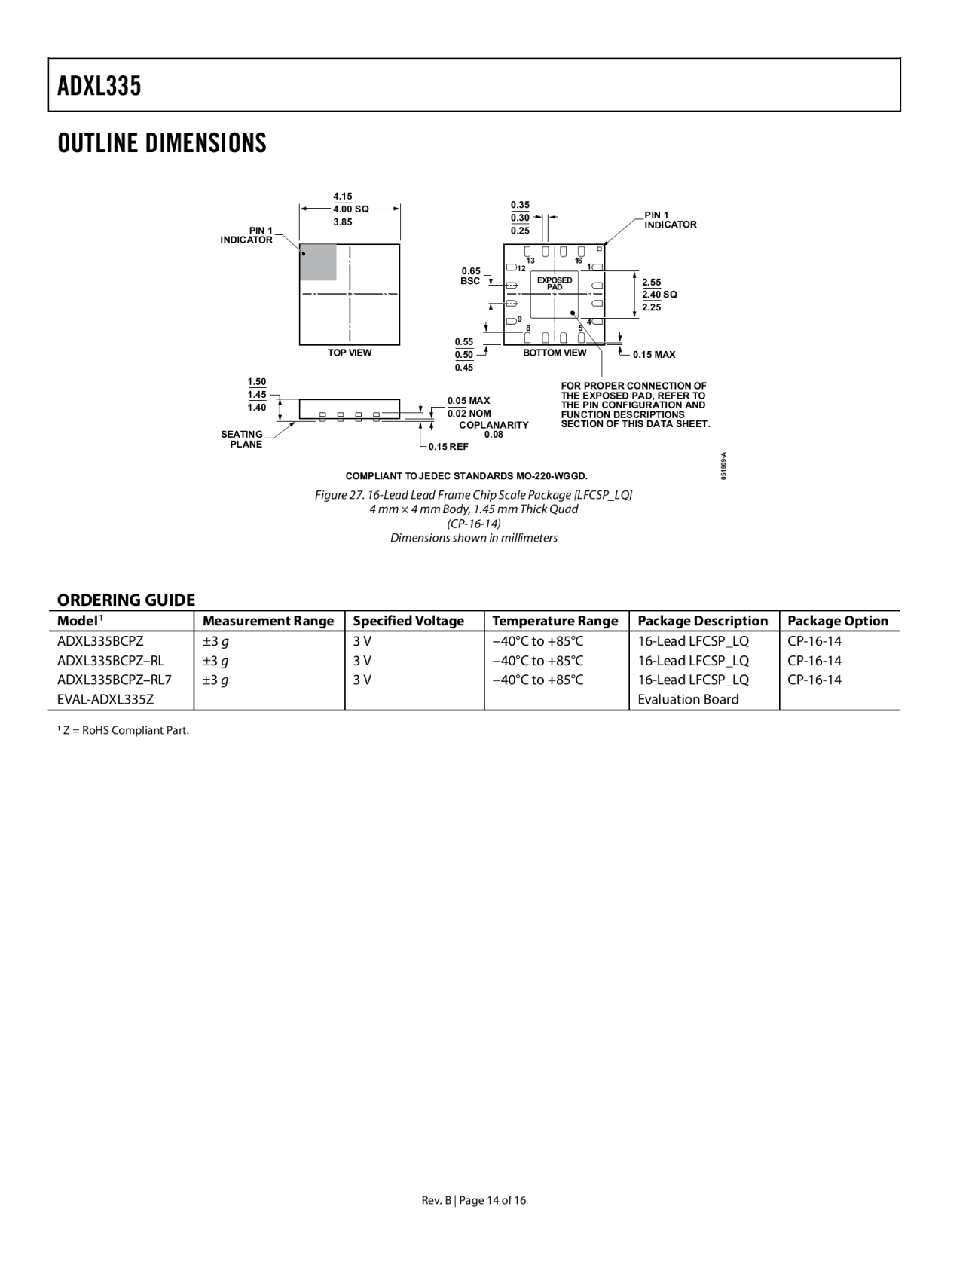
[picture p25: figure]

## Datasheet del Sensor Ultrasonico 40 kHz

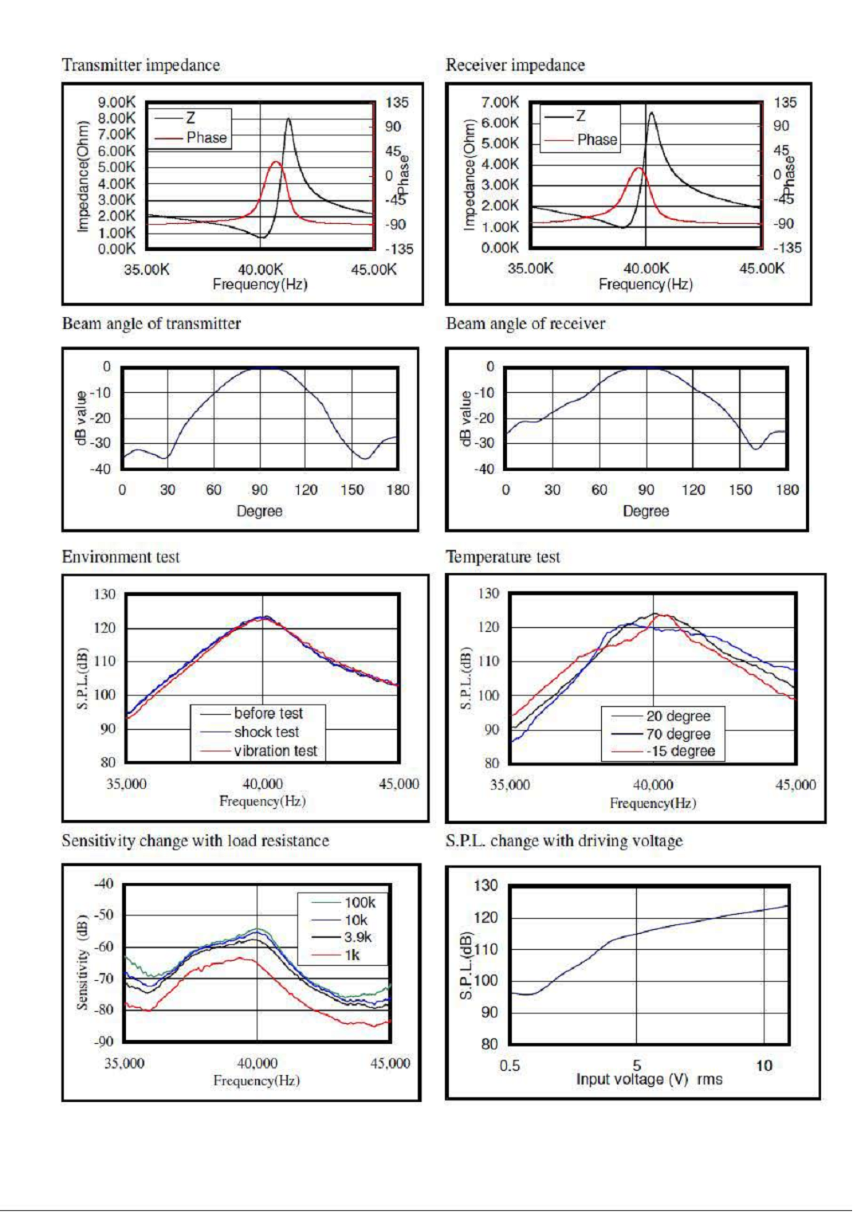
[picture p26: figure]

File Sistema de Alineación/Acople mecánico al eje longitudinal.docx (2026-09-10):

UNIVERSIDAD SIMÓN BOLÍVAR

EQUIPO BAJA SAE USB

DIVISIÓN DE ELECTRÓNICA

DIVISIÓN DE SUSPENSIÓN

# Portada

Acople Mecánico del Sistema de Alineación

Por:

Leonardo Jesús Ward Valdez

Sartenejas, Enero de 2014

Acople Mecánico del Sistema de Alineación

Acople al Eje Longitudinal

Para ajustar los sensores de ultrasonido al eje longitudinal del carro, se diseñó el siguiente acople mecánico:


Dicho acople se compone de las siguientes partes:

1 Lámina base:


Es esta lámina se encuentran los sensores de ultrasonido (emisor y receptor). En la imagen los sensores están representados por pequeñas cajas ubicadas sobre las láminas. Además posee 4 Orejitas en las cuales se acoplan los brazos que están sujetos al carro.

2 Brazos de Agarre:


Estos brazos permiten que la lámina base se agarre a la parte inferior del carro. El brazo se compone de una serie de eslabones, de modo que se puede ajustar el tamaño del brazo. En un extremo del brazo se sujeta a la lámina base y en el otro se coloca una pinza que se sujetará a los tubos del carro.

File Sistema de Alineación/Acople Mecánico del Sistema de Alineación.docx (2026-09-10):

UNIVERSIDAD SIMÓN BOLÍVAR

EQUIPO BAJA SAE USB

DIVISIÓN DE ELECTRÓNICA

DIVISIÓN DE SUSPENSIÓN

# Portada

Acople Mecánico del Sistema de Alineación

Por:

Leonardo Jesús Ward Valdez

Sartenejas, Octubre de 2013

Acople Mecánico del Sistema de Alineación

Para ajustar todo el sistema de alineación al carro utilizaremos 4 estructuras a las que llamaremos pinzas por su similitud con la forma de una pinza, y el uso de un resorte helicoidal para mantenerla sujeta al caucho. A continuación se muestran unas imágenes de la pinza que se sujetará al caucho.


Posiciones de la pinza

Cada pinza consta de varias piezas, entre las cuales tenemos, los brazos, el resorte helicoidal, un tubo que servirá de eje y unos tapones para cerrar el interior del eje. Algunas de las piezas se muestran en la siguiente figura.


Piezas que conforman la Pinza

En ambos extremos de dicha pinza se colocará el circuito de los sensores de ultrasonido, que se van a encargar de medir la distancias necesarias, en la siguiente imagen se muestran los lugares donde se colocarán dichos sensores en la pinza.


Posición de los Sensores de Ultrasonido en la Pinza

Para sujetar el acelerómetro a la pinza utilizaremos una lámina que estará sujeta (con tornillos) a la pinza en ambos brazos, de modo que el acelerómetro se pueda colocar fijo, y sea más fácil posicionar los ejes para medir los ángulos de inclinación.


Cara externa del Acople del Sistema de Alineación para el Carro

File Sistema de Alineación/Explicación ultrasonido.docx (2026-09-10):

Déjame hacer una pequeña explicación

Las primeras dos fotos son el resultado de lo que logré recopilar, valores calculados y todo.

Y la última son las referencias, por si las quieres revisar

Hay dos diagramas de bloques. Uno para el transmisor, y uno para el receptor. Luego de los diagramas escribí las opciones que hay para llenar el rol de cada uno de los bloques

Si la información era suficiente, también se incluía un esquemático y algunos comentarios al respecto

Cómo te daras cuenta, sólo llegué al primer bloque del receptor

Las referencias fueron: 2 notas de aplicación (una de Texas instruments y otra ... no recuerdo de quién) un par de manuales de un switch ultrasónico que vendian por ebay. Y una página que me ayudó a calcular los valores de los componentes del 555, porque yo soy muy flojo como para hacerlo.

También averigué qué eran las capsulitas que compraste, pero eso no lo incluí

(Curisamente esa información la hallé en un foro, en un post de un profesor de Sirilanka

Alguna pregunta? Duda, comentario, sugerencia o queja?

¿qué son las capsulitas que compré?

Son transductores piezo-eléctricos capacitivos

Con una frecuencia de resonancia de 40khz

Funcionan así: Tienes una laminita de material piezo electrico (si lo doblas produce una diferencia de potencial, y si le pones una diferencia de potencial, se dobla)

Entonces le pones 5v, se dobla un poco, le pones 0v se pone recto. Haces eso muy rápido, y tienes un pedacito de metal vibrando a 40khz

La corriente la medio ignoras, de todas maneras, a Vpp = 20v @ 40khz, traga que si 20mA

cuando el circuito es analógico... hay que hacer como 10 veces más pruebas que con los digitales

Por ejemplo

Entre las cosas que hay que hacer

Es conectar las capsulas a un generador de funciones y conseguir su punto real de resonancia

Luego ajustar el oscilador del 555 (probablemente con un potenciometro o una decada de resistencias) para que oscile precisamente a esa frecuencia

Obtener la impedancia de la capsula a la frecuencia de resonancia

Ajustar el amplificador del receptor (de nuevo con un osciloscopio y una decada) para que bote el voltaje que necesitamos a la distancia máxima de medición (lo más probable es que terminemos necesitando que se sature en ese punto

Si se puede, hacer una gráfica de voltaje del receptor vs. Distancia

Ajustar el filtro pasabanda para que resuene justo a la frecuencia del transmisor

Ajustar la Q del filtro para que sea lo más alta posible

...y creo que ajustar el comparador para que no se dispare por ruido.

... entre otras cosas que se podrían intentar hacer para tenerlo funcionando a punto.. (que entiendo que esa es la prioridad)

Dado una alimentacion de Vcc = 5v

El driver simple puede proveer a la carga con Vpp (pico pico) = 5v

El driver doble, por la forma tan peculiar que tiene, puede proveer 10v pico pico

Así que para una alimentación fija, el driver doble es el cuadruple de potente

En terminos de generación acústica

si necesitas reportar el tipo de OPAMP, di que vas a usar el TL072 de texas instruments. Ese debería dar la talla para todos los circuitos. Y si las cosas salen mal y terminas necesitando conseguirlos en serio. Yo te los puedo vender, que tengo como 40 de ellos

no se si los venden aqui, pero cuestan como 60 centavos cada uno

Transmisor:

-Generador 555 con driver simple

-Generador 555 con driver doble

-Generador de Cristal con driver simple

-Generador de Cristal con driver doble

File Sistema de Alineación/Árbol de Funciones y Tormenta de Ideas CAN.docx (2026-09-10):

Árbol de Funciones


Flujograma

1. Montar al piloto en el carro
2. Nivelación del carro
3. Acoplar dispositivos a cada rueda
4. Conectar (cablear) los distintos dispositivos
5. Energizar
6. Encender
7. Activar ultrasonidos
8. Revisar información de mediciones
9. Colocar configuración deseada
10. Leer indicaciones
11. Configurar las mesetas o los brazos
12. Repetir 10 y 11 hasta tener la configuración deseada
13. Apagar
14. Remover dispositivos del carro

Configurador de Ángulos de Neumáticos CAN
Mediciones de Ángulos
Camber
Toe
Fácil Ensamblaje
Liviano
Pocas Piezas
Acople con la rueda
Despkegable
Aislamiento
Agua
Calor
Ruido
Adaptable
Cualquier Terreno
Cualquier caucho
Potencia mínima
Mantenimiento Mínimo
Respuesta Dinámica
Ganancia de Camber
Fácil Interfaz
Indicaciones
Gráficos
Información
Alarma
Configurable
Tormenta de Ideas

Medición de Ángulos de Ruedas
Lineas en el piso
Conos
Fácil Interfaz
Pantallas
Ultrasonido
Transportador
Regla
Brazo de la misma longitud acoplado al chasis
Lámina de referencia
Soporte guía
Laser
Infrarrojo
Cables
Sistemas ópticos
Medidor de inclinación
Giroscopio
Medidor de Nivel
Acelerómetro
Pared
Sensores
Cinta métrica
GPS
Ojo por ciento
Fotos
Sonidos
Gráficos, dibujos
Automático
Computadora (labview)
Aplicación Android
Pocos Botones
Configuraciones Pre-establecidas
Usuario entrenado
Información del valor real (técnica)
Sistema de luces (toe in, toe out) Sin pantalla
Respuesta dinámica
Definir límite físico
Fácil configuración de brazos de suspensión
Voz
Holograma
Ganancia de Ángulos

Potencia mínima
Paneles Solares
Fácil ensamblaje
Pocas piezas
Bicicletas
Turbinas eólicas
Alternador
Pila
Descargas eléctricas
Disminuir pérdidas (menos cables)
Boton de encendido y apagado
Cantidad vital de dispositivos en funcionamiento
Limitar energía que necesita
Desconectar secciones que no están en uso
Energía mínima requerida para generar una onda
Acoplamientos temporales
Pinzas, roscas
Pre-armado
Dividir en subsistemas
Poco volumen y peso
Poco ajustable al carro
Fácil interfaz
Desplegable
Inflable
Manual
Auto-armado
No depende del chasis

Adaptable
Pocos puntos de apoyo en el suelo
Aislamiento
Encapsulado para la electrónica
Correas
Pinzas
Sin apoyo en el caucho
Articulaciones
Aislar medio por tubos
Onda a una frecuencia distinta a los sonidos cotidianos
Liviano
Sellado
Interfáz gráfica
Rápido
Tubos para ultrasonido
Aumentar resistencia
Alinear en la caja del carro
Sellar mecanicamente contra fluido
Aerodinámico
Toldo
Embudo guía
Barrera o destruir objetos cercanos
Configurar altura
Otra frecuencia
Meterle resistencia para mantener temperatura constante
Ajuste automático

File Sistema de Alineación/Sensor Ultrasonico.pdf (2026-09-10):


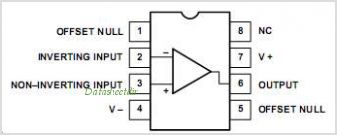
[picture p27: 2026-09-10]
Sistema de Alineación/NXP-UA741-pinout.jpg

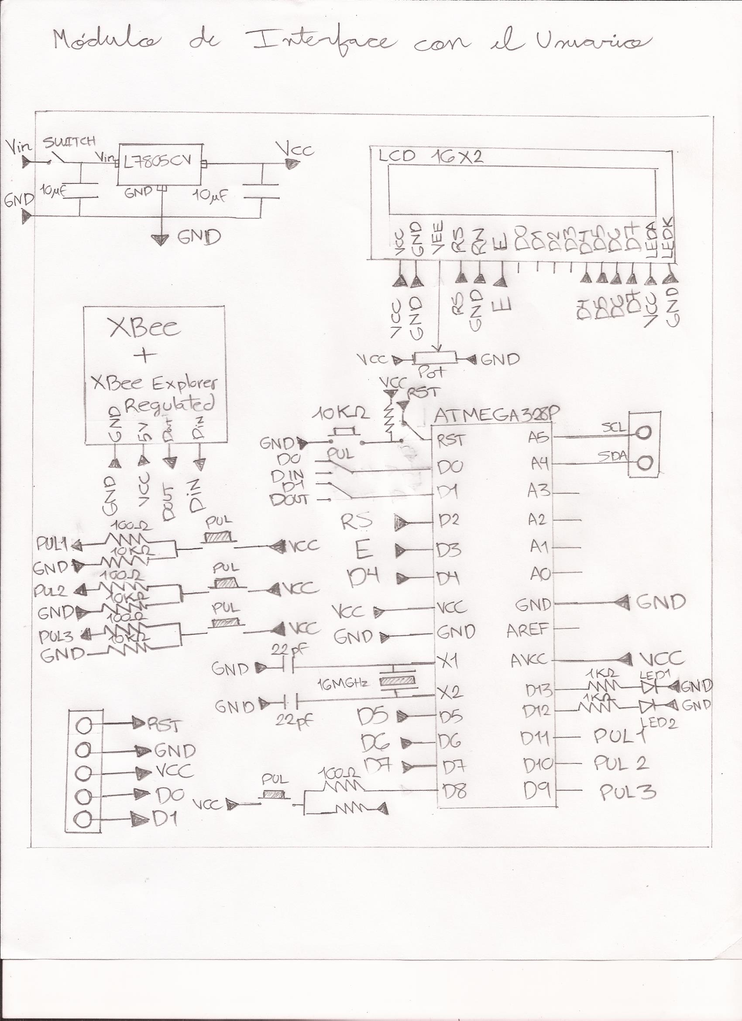
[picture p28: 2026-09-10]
Sistema de Alineación/Módulo de interface con el usuario.jpg

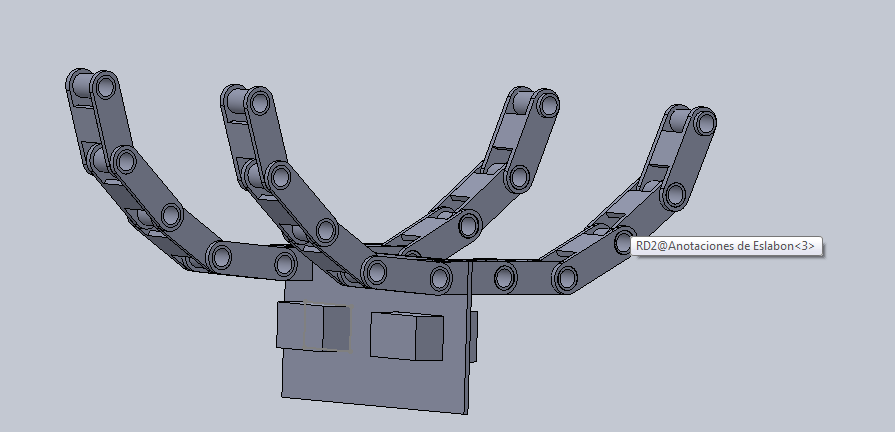
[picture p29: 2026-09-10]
Sistema de Alineación/Acople con eje longitudinal/Acople a eje longitudinal.png

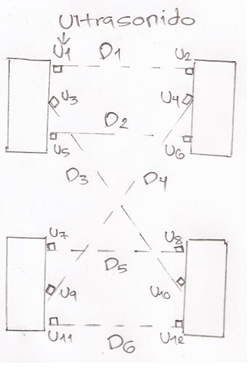
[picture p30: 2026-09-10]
Sistema de Alineación/Ultrasonido.png

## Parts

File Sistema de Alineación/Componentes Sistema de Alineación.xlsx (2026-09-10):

Sistema de Alineación
Artículo | Precio por unidad (Bsf) | Cantidad | Total (Bsf) | Ubicación
Regulador de Voltaje 5V 7805 | 10 | 6 | 60 | http://www.electronica.com.ve//ventas/catalog/product_info.php?products_id=83
Regulador de Voltaje 3.3V - 78M33C | 24 | 5 | 120 | http://www.electronicamagnabit.com/tienda/reguladores/176-regulador-de-voltaje-33v-78m33c.html
Switch | 8.5 | 2 | 17 | http://www.electronicamagnabit.com/tienda/switch-pulsadores/125-switch-2-posiciones-2-pines.html
Pulsador Grande | 20 | 4 | 80 | http://www.electronicamagnabit.com/tienda/switch-pulsadores/1401-pulsador-para-empotrar-3a.html
LCD 16x2 | 175 | 1 | 175 | http://www.electronicamagnabit.com/tienda/display-lcd/27-lcd-16x2-con-backlight.html
Módulo Xbee 1mW | 770 | 2 | 1540 | http://www.electronicamagnabit.com/tienda/modulos/459-modulo-xbee-1mw-con-antena-chip-2-4ghz.html
Xbee Explorer Regulated | 320 | 2 | 640 | http://www.electronicamagnabit.com/tienda/kits-rf/469-xbee-explorer-regulated.html
Potenciometro 10KΩ | 12 | 1 | 12 | http://www.electronicamagnabit.com/tienda/potenciometros-trimmers/555-potenciometro-10k.html
ATMEGA328 con Bootloader | 230 | 6 | 1380 | http://www.electronicamagnabit.com/tienda/arduino/520-arduino-atmega328-con-bootloader.html
Pulsador para PCB 6x6mm | 4 | 6 | 24 | http://www.electronicamagnabit.com/tienda/switch-pulsadores/670-pulsador-para-pcb.html
Resistencia 1KΩ (paquete de 10) | 0.4 | 80 | 32 | http://www.electronicamagnabit.com/tienda/resistencias/961-pack-10-resistencias-1k-1-8watts.html
Resistencia 10KΩ (paquete de 10) | 0.4 | 41 | 16.4 | http://www.electronicamagnabit.com/tienda/resistencias/961-pack-10-resistencias-1k-1-8watts.html
Resistencia 100Ω (paquete de 10) | 0.4 | 5 | 2 | http://www.electronicamagnabit.com/tienda/resistencias/961-pack-10-resistencias-1k-1-8watts.html
Leds Multicolores 3mm | 1 | 25 | 25 | http://www.electronicamagnabit.com/tienda/leds/82-led-3mm-rojo-standard.html
Cristal 16MHz | 9 | 6 | 54 | http://www.electronicamagnabit.com/tienda/cristales/180-cristal-16mhz.html
Condensador Ceramico 22pF/50V | 2 | 6 | 12 | http://www.electronicamagnabit.com/tienda/ceramicos/356-condensador-ceramico-22pf-50v.html
Condensador Ceramico 4,7nF | 2 | 6 | 12 | http://www.electronicamagnabit.com/tienda/ceramicos/1165-condensador-ceramico-47nf-50v.html
Conector Header Hembra 8 pines | 9 | 6 | 54 | http://www.electronicamagnabit.com/tienda/conectores-adaptadores/444-conector-header-hembra-8-pines.html
Baquelita Perforada 14x11 cms | 65 | 7 | 455 | http://www.electronicamagnabit.com/tienda/pcb/697-lamina-baquelita-perforada-14x11-cms.html
Sensor Ultrasonico 40 kHz (EL PAR) | 170 | 8 | 1360 | http://www.electronicamagnabit.com/tienda/sensores/348-sensor-ultrasonico-40-khz.html
LM555 Timer | 9 | 8 | 72 | http://www.electronicamagnabit.com/tienda/circuitos-integrados/202-lm-555-timer.html
74LS14 Inversor Schmitt trigger | 20 | 8 | 160 | http://www.electronicamagnabit.com/tienda/ttl-cmos/1173-74ls14-inversor-schmitt-trigger.html
MAX232 | 20 | 8 | 160 | http://www.electronicamagnabit.com/tienda/circuitos-integrados/373-max232.html
Condensador Ceramico 0,1uF/50V | 3 | 16 | 48 | http://www.electronicamagnabit.com/tienda/ceramicos/760-condensador-ceramico-01uf-50v-multicapa.html
Condensador Ceramico 0,01uF/50V | 2 | 8 | 16 | http://www.electronicamagnabit.com/tienda/ceramicos/728-condensador-ceramico-001uf-50v.html
Acelerometro Triple Axis ADXL335 | 950 | 4 | 3800 | http://www.electronica.com.ve//ventas/catalog/product_info.php?products_id=2691
 |  | Total (Bsf) | 10326.4
Cosas que tenemos
Sistema de Alineación
Artículo | Precio por unidad (Bsf) | Cantidad | Total (Bsf) | Ubicación
Switch | 8.5 | 2 | 17 | http://www.electronicamagnabit.com/tienda/switch-pulsadores/125-switch-2-posiciones-2-pines.html
Pulsador Grande | 20 | 4 | 80 | http://www.electronicamagnabit.com/tienda/switch-pulsadores/1401-pulsador-para-empotrar-3a.html
LCD 16x2 | 175 | 1 | 175 | http://www.electronicamagnabit.com/tienda/display-lcd/27-lcd-16x2-con-backlight.html
Módulo Xbee 1mW | 770 | 2 | 1540 | http://www.electronicamagnabit.com/tienda/modulos/459-modulo-xbee-1mw-con-antena-chip-2-4ghz.html
Xbee Explorer Regulated | 320 | 2 | 640 | http://www.electronicamagnabit.com/tienda/kits-rf/469-xbee-explorer-regulated.html
Acelerometro Triple Axis ADXL335 | 950 | 4 | 3800 | http://www.electronica.com.ve//ventas/catalog/product_info.php?products_id=2691
Sensor Ultrasonico 40 kHz (EL PAR) | 170 | 2 | 340 | http://www.electronicamagnabit.com/tienda/sensores/348-sensor-ultrasonico-40-khz.html
 |  | Total (Bsf) | 6592
Cosas que necesitamos
Sistema de Alineación
Artículo | Precio por unidad (Bsf) | Cantidad | Total (Bsf) | Ubicación
Regulador de Voltaje 5V 7805 | 10 | 6 | 60 | http://www.electronica.com.ve//ventas/catalog/product_info.php?products_id=83
Regulador de Voltaje 3.3V - 78M33C | 24 | 5 | 120 | http://www.electronicamagnabit.com/tienda/reguladores/176-regulador-de-voltaje-33v-78m33c.html
ATMEGA328 con Bootloader | 230 | 6 | 1380 | http://www.electronicamagnabit.com/tienda/arduino/520-arduino-atmega328-con-bootloader.html
Pulsador para PCB 6x6mm | 4 | 6 | 24 | http://www.electronicamagnabit.com/tienda/switch-pulsadores/670-pulsador-para-pcb.html
Resistencia 1KΩ (paquete de 10) | 0.4 | 80 | 32 | http://www.electronicamagnabit.com/tienda/resistencias/961-pack-10-resistencias-1k-1-8watts.html
Resistencia 10KΩ (paquete de 10) | 0.4 | 41 | 16.4 | http://www.electronicamagnabit.com/tienda/resistencias/961-pack-10-resistencias-1k-1-8watts.html
Resistencia 100Ω (paquete de 10) | 0.4 | 5 | 2 | http://www.electronicamagnabit.com/tienda/resistencias/961-pack-10-resistencias-1k-1-8watts.html
Leds Multicolores 3mm | 1 | 25 | 25 | http://www.electronicamagnabit.com/tienda/leds/82-led-3mm-rojo-standard.html
Cristal 16MHz | 9 | 6 | 54 | http://www.electronicamagnabit.com/tienda/cristales/180-cristal-16mhz.html
Condensador Ceramico 22pF/50V | 2 | 6 | 12 | http://www.electronicamagnabit.com/tienda/ceramicos/356-condensador-ceramico-22pf-50v.html
Condensador Ceramico 4,7nF | 2 | 6 | 12 | http://www.electronicamagnabit.com/tienda/ceramicos/1165-condensador-ceramico-47nf-50v.html
Conector Header Hembra 8 pines | 9 | 6 | 54 | http://www.electronicamagnabit.com/tienda/conectores-adaptadores/444-conector-header-hembra-8-pines.html
Baquelita Perforada 14x11 cms | 65 | 7 | 455 | http://www.electronicamagnabit.com/tienda/pcb/697-lamina-baquelita-perforada-14x11-cms.html
Sensor Ultrasonico 40 kHz (EL PAR) | 170 | 6 | 1020 | http://www.electronicamagnabit.com/tienda/sensores/348-sensor-ultrasonico-40-khz.html
LM555 Timer | 9 | 8 | 72 | http://www.electronicamagnabit.com/tienda/circuitos-integrados/202-lm-555-timer.html
74LS14 Inversor Schmitt trigger | 20 | 8 | 160 | http://www.electronicamagnabit.com/tienda/ttl-cmos/1173-74ls14-inversor-schmitt-trigger.html
MAX232 | 20 | 8 | 160 | http://www.electronicamagnabit.com/tienda/circuitos-integrados/373-max232.html
Condensador Ceramico 0,1uF/50V | 3 | 16 | 48 | http://www.electronicamagnabit.com/tienda/ceramicos/760-condensador-ceramico-01uf-50v-multicapa.html
Condensador Ceramico 0,01uF/50V | 2 | 8 | 16 | http://www.electronicamagnabit.com/tienda/ceramicos/728-condensador-ceramico-001uf-50v.html
 |  | Total (Bsf) | 3722.4
Compras con 300
Sistema de Alineación
Artículo | Precio por unidad (Bsf) | Cantidad | Total (Bsf) | Ubicación
MAX232 | 20 | 4 | 80 | http://www.electronicamagnabit.com/tienda/circuitos-integrados/373-max232.html
Transistor NPN 2n3904 | 2.5 | 8 | 20 | http://www.electronicamagnabit.com/tienda/transistores/23-transistor-npn-2n3904.html
Cristal 16MHz | 9 | 2 | 18 | http://www.electronicamagnabit.com/tienda/cristales/180-cristal-16mhz.html
LM555 Timer | 9 | 4 | 36 | http://www.electronicamagnabit.com/tienda/circuitos-integrados/202-lm-555-timer.html
Resistencia 1KΩ (paquete de 10) | 4 | 6 | 24 | http://www.electronicamagnabit.com/tienda/resistencias/961-pack-10-resistencias-1k-1-8watts.html
Resistencia 10KΩ (paquete de 10) | 4 | 3 | 12 | http://www.electronicamagnabit.com/tienda/resistencias/961-pack-10-resistencias-1k-1-8watts.html
Resistencia 100Ω (paquete de 10) | 4 | 2 | 8 | http://www.electronicamagnabit.com/tienda/resistencias/961-pack-10-resistencias-1k-1-8watts.html
Condensador Ceramico 22pF/50V | 2 | 6 | 12 | http://www.electronicamagnabit.com/tienda/ceramicos/356-condensador-ceramico-22pf-50v.html
Condensador Ceramico 4,7nF | 2 | 4 | 8 | http://www.electronicamagnabit.com/tienda/ceramicos/1165-condensador-ceramico-47nf-50v.html
Condensador Ceramico 0,1uF/50V | 3 | 4 | 12 | http://www.electronicamagnabit.com/tienda/ceramicos/760-condensador-ceramico-01uf-50v-multicapa.html
Condensador Ceramico 0,01uF/50V | 2 | 4 | 8 | http://www.electronicamagnabit.com/tienda/ceramicos/728-condensador-ceramico-001uf-50v.html
TL082 Amplificador Operacional Dual | 15 | 4 | 60 | http://www.electronicamagnabit.com/tienda/circuitos-integrados/199-tl082-amplificador-operacional.html
 |  | Total | 298

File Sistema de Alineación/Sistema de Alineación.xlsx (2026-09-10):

Sistema de Alineación
Imagen | Nombre | Link | Precio por unidad | Cantidad | Total
 | Sensor Ultrasonico 40 kHz (EL PAR) | http://www.electronicamagnabit.com/tienda/sensores/348-sensor-ultrasonico-40-khz.html | 170 | 6 | 1020
 | Modulo Sensor Acelerometro Triple Axis ADXL335 | http://www.electronica.com.ve//ventas/catalog/product_info.php?cPath=50&products_id=2691 (http://www.electronica.com.ve/ventas/catalog/product_info.php?cPath=50&products_id=2691) | 950 | 4 | 3800
Valor Final |  |  |  |  | 4820

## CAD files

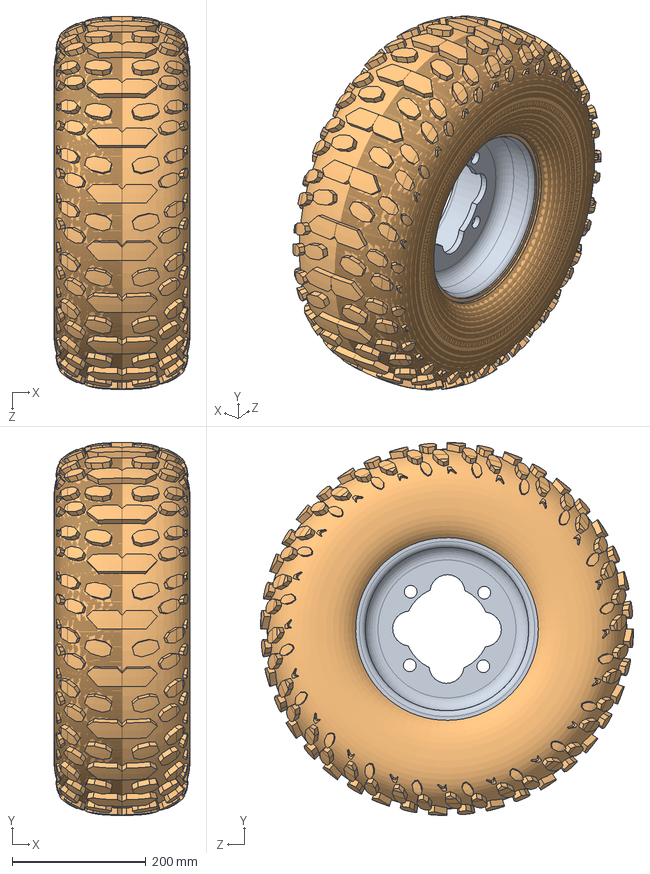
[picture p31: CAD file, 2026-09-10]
Sistema de Alineación/Acople con las Ruedas/caucho.SLDASM
203.7 x 558.8 x 558.8 mm
Rin Trasero Douglas 3+2
GoodYear WS_atv22x8r10

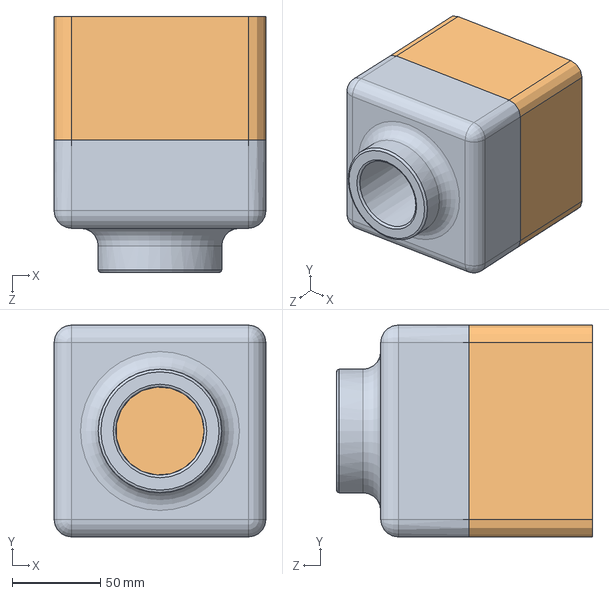
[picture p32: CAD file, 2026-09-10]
Sistema de Alineación/Tutoriales/Tutorial.SLDASM
120.0 x 120.0 x 145.0 mm
Tutor1
Tutor2

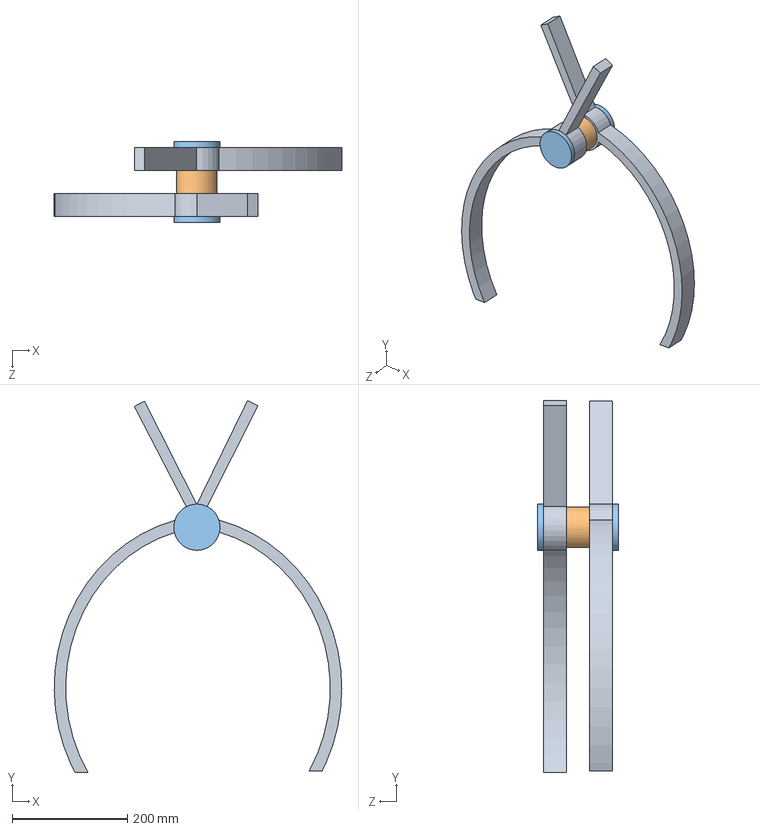
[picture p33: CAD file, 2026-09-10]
Sistema de Alineación/Acople con las Ruedas/Ensamblaje1.SLDASM
498.5 x 644.9 x 140.0 mm
Pinza1 x 2
Tubo Eje
Tapones Tubo Eje x 2

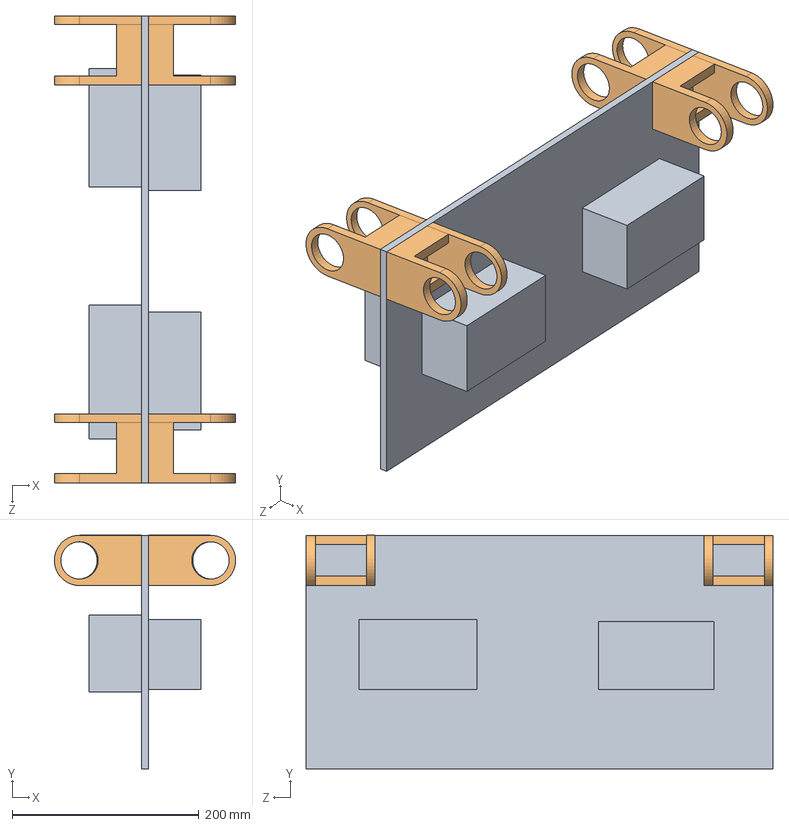
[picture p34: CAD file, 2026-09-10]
Sistema de Alineación/Acople con eje longitudinal/Base.SLDASM
194.0 x 250.0 x 500.0 mm
Lámina
Orejita x 4

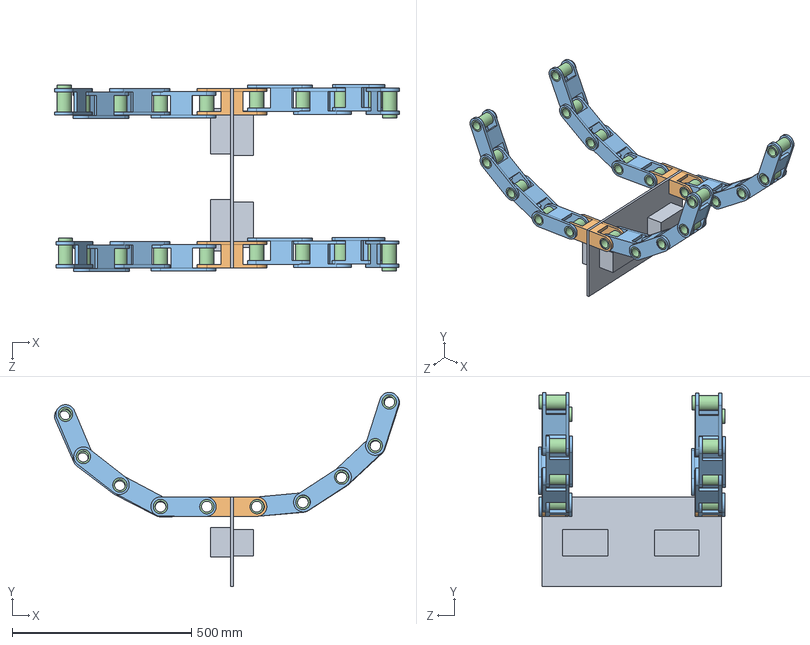
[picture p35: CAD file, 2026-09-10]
Sistema de Alineación/Acople con eje longitudinal/Acople a eje longitudinal.SLDASM
961.2 x 541.8 x 521.0 mm
Lámina
Orejita x 4
Eslabon x 16
Tubo Eje Eslabon x 20

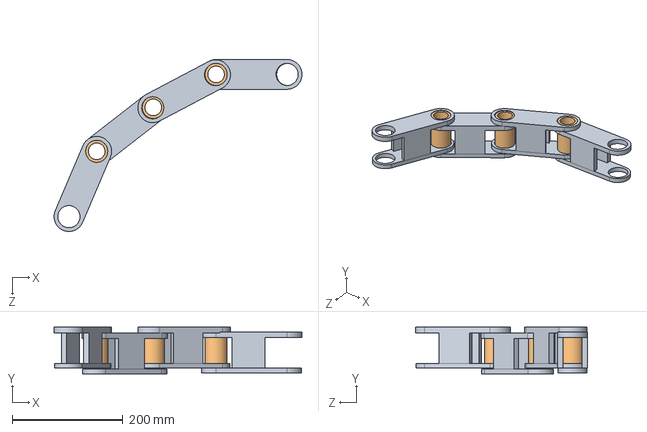
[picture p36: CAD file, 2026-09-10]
Sistema de Alineación/Acople con eje longitudinal/Cadena.SLDASM
447.2 x 84.0 x 310.2 mm
Eslabon x 4
Tubo Eje Eslabon x 3

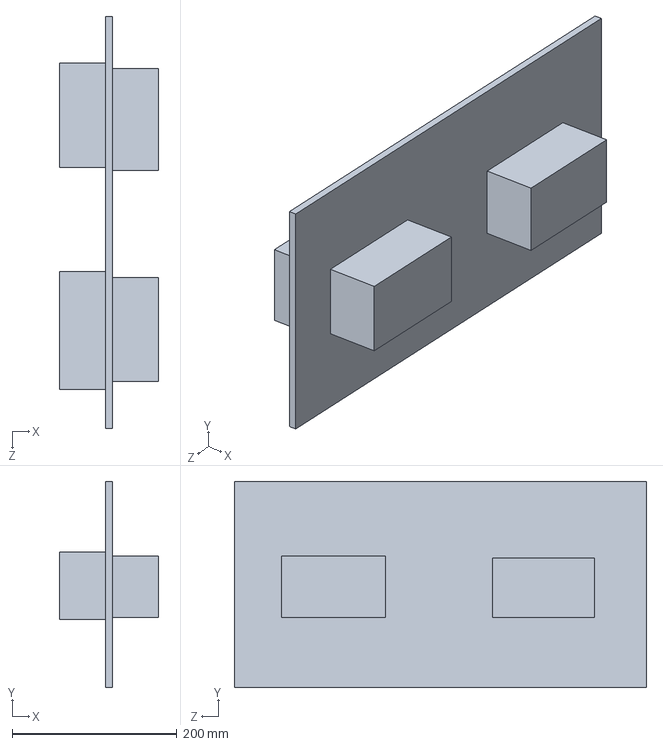
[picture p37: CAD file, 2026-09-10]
Sistema de Alineación/Acople con eje longitudinal/Lámina.SLDPRT
120.0 x 250.0 x 500.0 mm

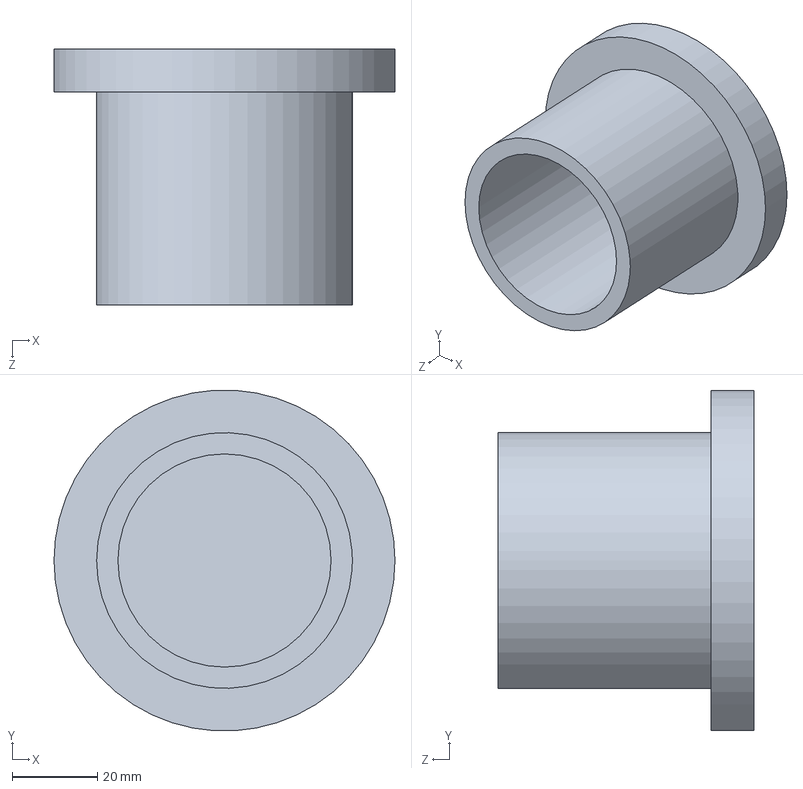
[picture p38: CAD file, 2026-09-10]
Sistema de Alineación/Acople con eje longitudinal/Tapones Tubo Eje Eslabon.SLDPRT
80.0 x 79.8 x 60.0 mm

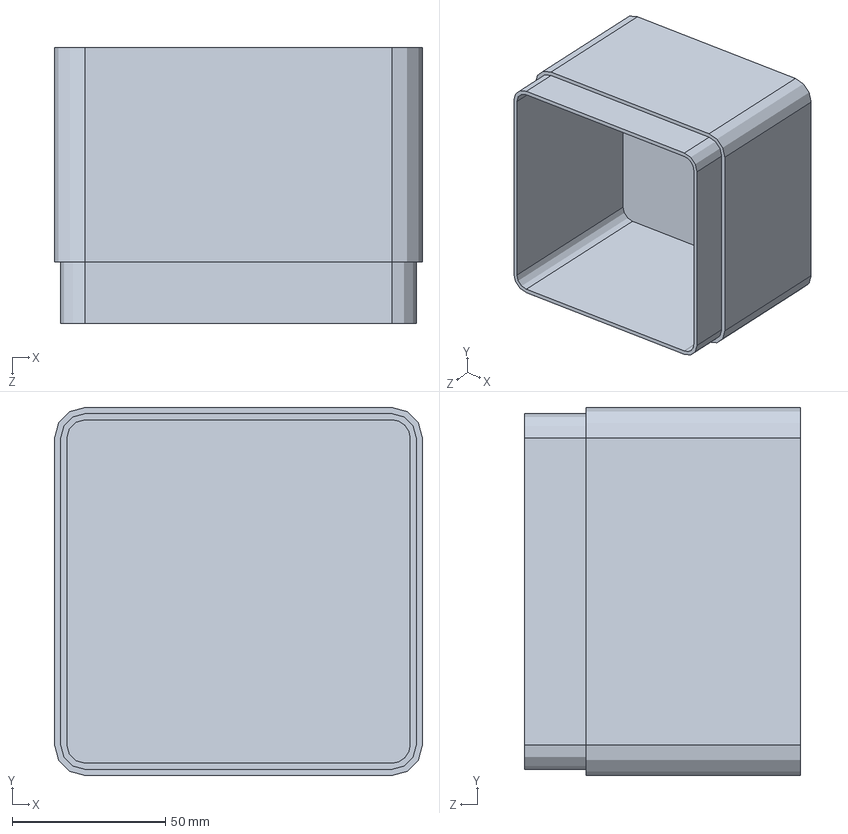
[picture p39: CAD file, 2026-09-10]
Sistema de Alineación/Tutoriales/Tutor2.SLDPRT
120.0 x 120.0 x 90.0 mm

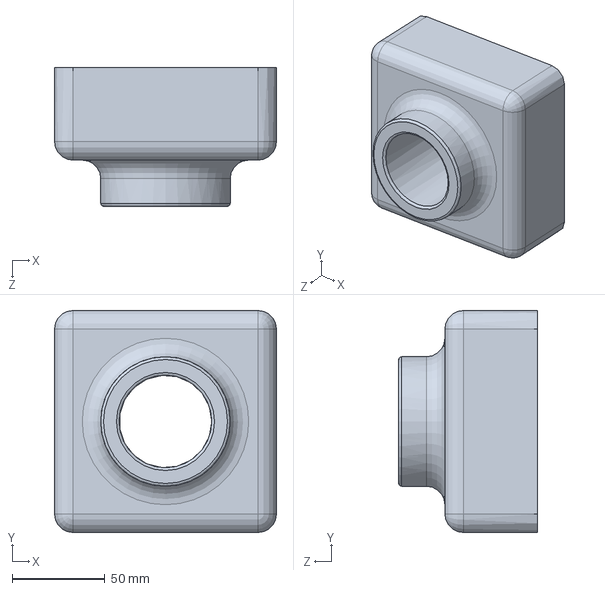
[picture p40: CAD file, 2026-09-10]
Sistema de Alineación/Tutoriales/Tutor1.SLDPRT
120.0 x 120.0 x 75.0 mm

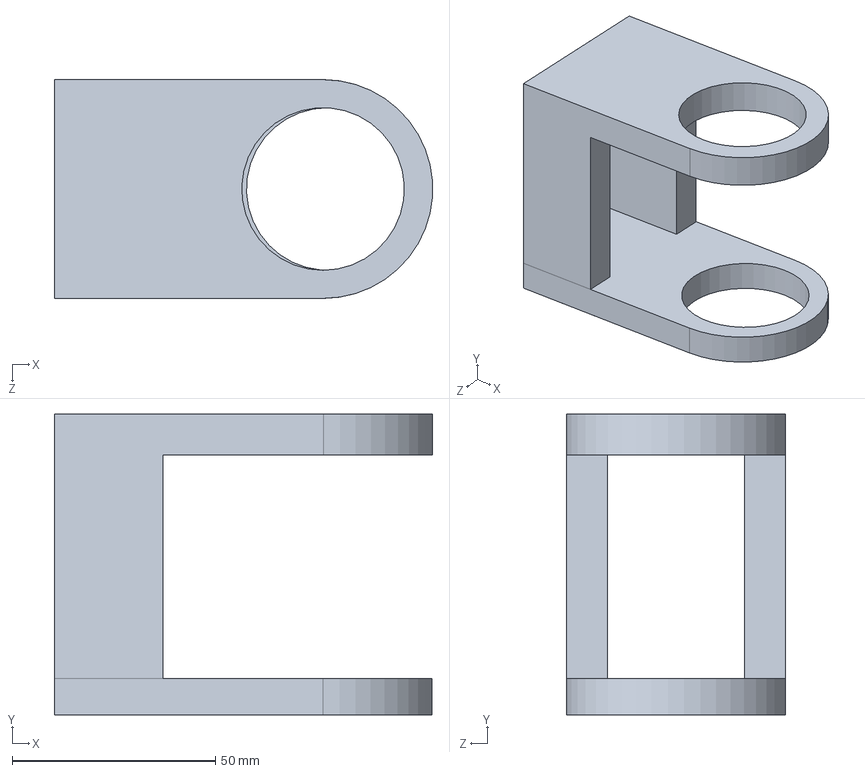
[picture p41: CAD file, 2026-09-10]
Sistema de Alineación/Acople con eje longitudinal/Orejita.SLDPRT
93.0 x 74.0 x 53.9 mm

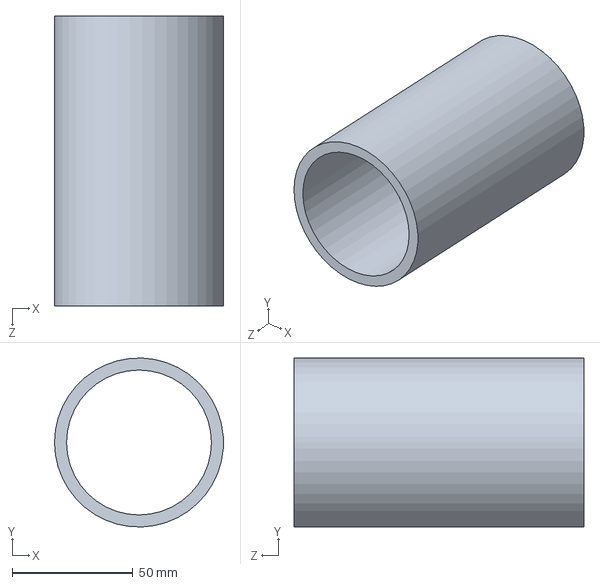
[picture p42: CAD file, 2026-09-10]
Sistema de Alineación/Acople con las Ruedas/Tubo Eje.SLDPRT
70.0 x 70.0 x 120.0 mm

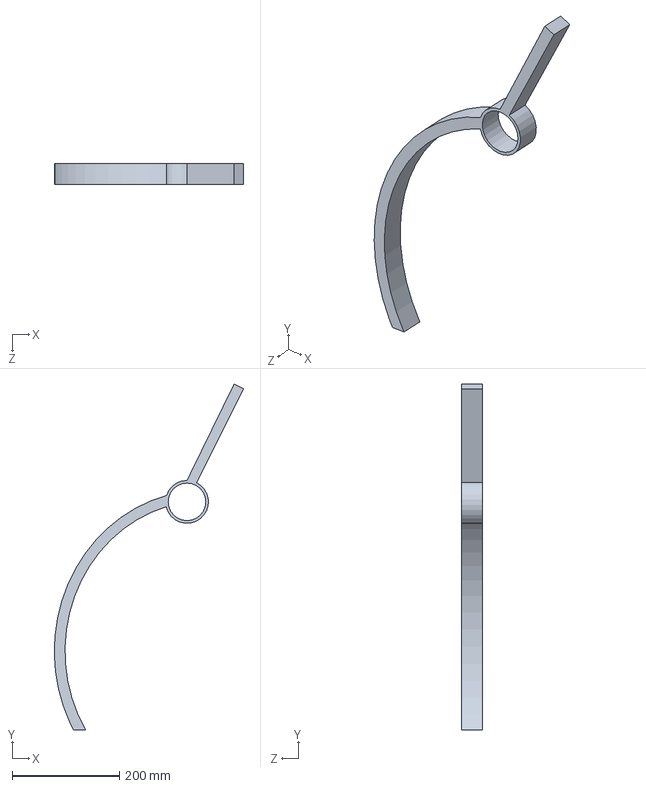
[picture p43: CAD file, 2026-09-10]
Sistema de Alineación/Acople con las Ruedas/Pinza1.SLDPRT
353.0 x 644.9 x 40.0 mm

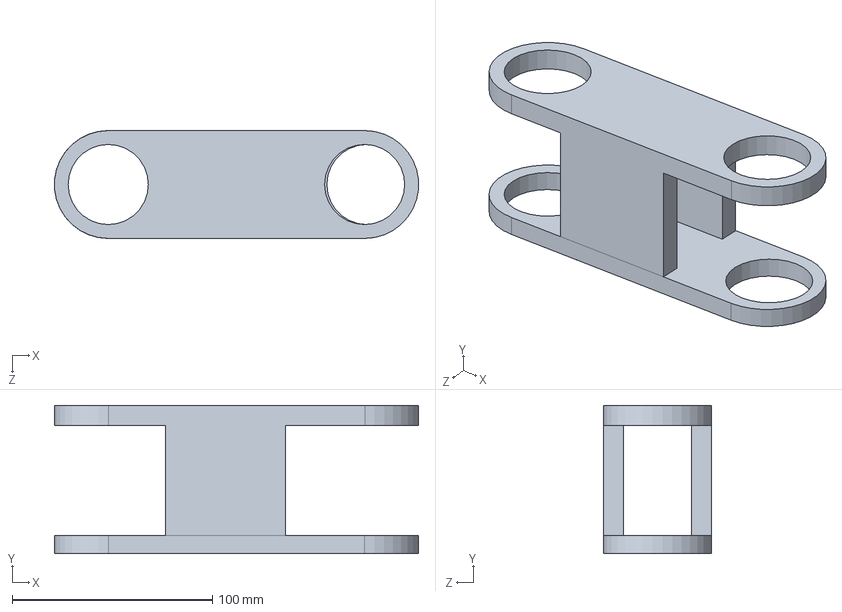
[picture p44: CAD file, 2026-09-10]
Sistema de Alineación/Acople con eje longitudinal/Eslabon.SLDPRT
181.7 x 74.0 x 53.9 mm

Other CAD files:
Sistema de Alineación/Acople con las Ruedas/Acople resorte a Pinza.SLDPRT
Sistema de Alineación/Acople con eje longitudinal/Tubo Eje Eslabon.SLDPRT

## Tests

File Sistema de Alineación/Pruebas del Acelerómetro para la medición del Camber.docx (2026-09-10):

PRUEBAS

- Cálculo del Camber (Acelerómetros)

Para realizar el cálculo del camber de la rueda, se utilizará el acelerómetro ADXL335:

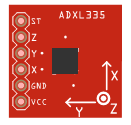
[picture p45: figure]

Este componente nos permite medir las aceleraciones en los 3 ejes y consta de 5 pines importantes:

-VCC= Alimentación (de 1.8 a 3.6 voltios)

-GND= Tierra

-X = Punto de lectura de aceleraciones del eje X

-Y = Punto de lectura de aceleraciones del eje Y

-Z = Punto de lectura de aceleraciones del eje Z

-ST= Self Test (no conectamos este pin)

Para poder medir un ángulo con respecto a la vertical, hacemos uso de la medición de la aceleración de la gravedad.

Marco Metodológico

Montaje del Circuito:

La salida de cada uno de los pines relacionados a cada eje ADXL335 tiene un voltaje proporcional a la aceleración medida, por lo que los conectamos a los pines A0,A1 y A2 del Arduino, ya que el microcontrolador posee ADC (conversor analógico-digital) en los pines que están conectados a esos puertos de la tarjeta por lo que podemos medir las variaciones del voltaje del ADXL335.

Además conectamos el puerto de 3.3V del Arduino a VCC del ADXL335, conectamos las tierras de los dispositivos a la tierra de la batería y el positivo a de la batería lo conectamos al puerto Vin del Arduino que está conectado a un regulador de voltaje que da los 5 voltios que necesita el microcontrolador y a otro que da los 3.3v que necesita el ADXL335 (los reguladores se encuentran en el Arduino). El montaje se muestra en las siguientes figuras.


Diagrama del montaje para las pruebas del ADXL335

El acelerómetro tiene un rango de desde -3g hasta 3g, situando el 0g en la mitad del voltaje de alimentación, es decir, si alimentamos el circuito con 3.3v entonces encontraremos 0g en 1,65 voltios. Además la escala del sensor también varía proporcionalmente con el voltaje de alimentación, si alimentamos el circuito con 3.3v el factor que define la escala es 330mV/g.Para probar el acelerómetro colocamos el sensor en distintas posiciones de modo que registre la aceleración de la gravedad (1g) en un eje distinto en cada oportunidad. Para determinar la posición del sensor nos guiamos por las siguientes imágenes sacadas del Datasheet del ADXL335. Del sensor medimos un voltaje, que el ADC del microcontrolador transforma en 10 bits, por lo que el obtenemos una lectura entre 0 y 1023.

Para obtener la lectura de la aceleración en m/s² utilizamos la siguiente ecuación:

En la ecuación la Lectura es la medida que obtiene el microcontrolador, que convertimos de un número de 10 bits en decimal (valor del voltaje en mV), luego le restamos el voltaje que tiene cuando ninguna aceleración actúa sobre él, (Voltaje0G=VoltajeAlimentación(mV)/2=1650mV), y lo dividimos entre el factor que determina la escala (VoltajeAlimentación(mV)/10=330mV) y lo multiplicamos con el valor de la gravedad G=9.80665m/s².

En las pruebas colocamos el sensor en las siguientes posiciones que nos permitirán medir el valor de la gravedad en los distintos ejes:


Resultados:

Probamos 3 posiciones, que se muestran a continuación:

| Posición 1

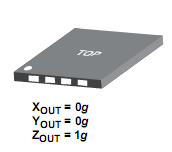
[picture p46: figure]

| Resultados Ideales | | Resultados Reales
Eje | Aceleración (G) | Aceleración (m/s²) | Voltaje (mV) | Aceleración (G) | Aceleración (m/s²)
X | 0 | 0 | 1739,98 | 0,27267 | 2,67395
Y | 0 | 0 | 1661,78 | 0,03570 | 0,35007
Z | 1 | 9,80665 | 2082,11 | 1,30942 | 12,84107

| Posición 2
| Resultados Ideales | | Resultados Reales
Eje | Aceleración (G) | Aceleración (m/s²) | Voltaje (mV) | Aceleración (G) | Aceleración (m/s²)
X | 0 | 0 | 1744,87 | 0,28748 | 2,81926
Y | 1 | 9,80665 | 2038,12 | 1,17612 | 11,53381
Z | 0 | 0 | 1739,98 | 0,27267 | 2,67395

| Posición 3
| Resultados Ideales | | Resultados Reales
Eje | Aceleración (G) | Aceleración (m/s²) | Voltaje (mV) | Aceleración (G) | Aceleración (m/s²)
X | 1 | 9,80665 | 2077,22 | 1,29461 | 12,69575
Y | 0 | 0 | 1691,1 | 0,12455 | 1,22137
Z | 0 | 0 | 1769,31 | 0,36155 | 3,54555

Conclusiones:

Se han obtenido los resultados esperados, pero es recomendable ajustar las mediciones para obtener valores más exactos.

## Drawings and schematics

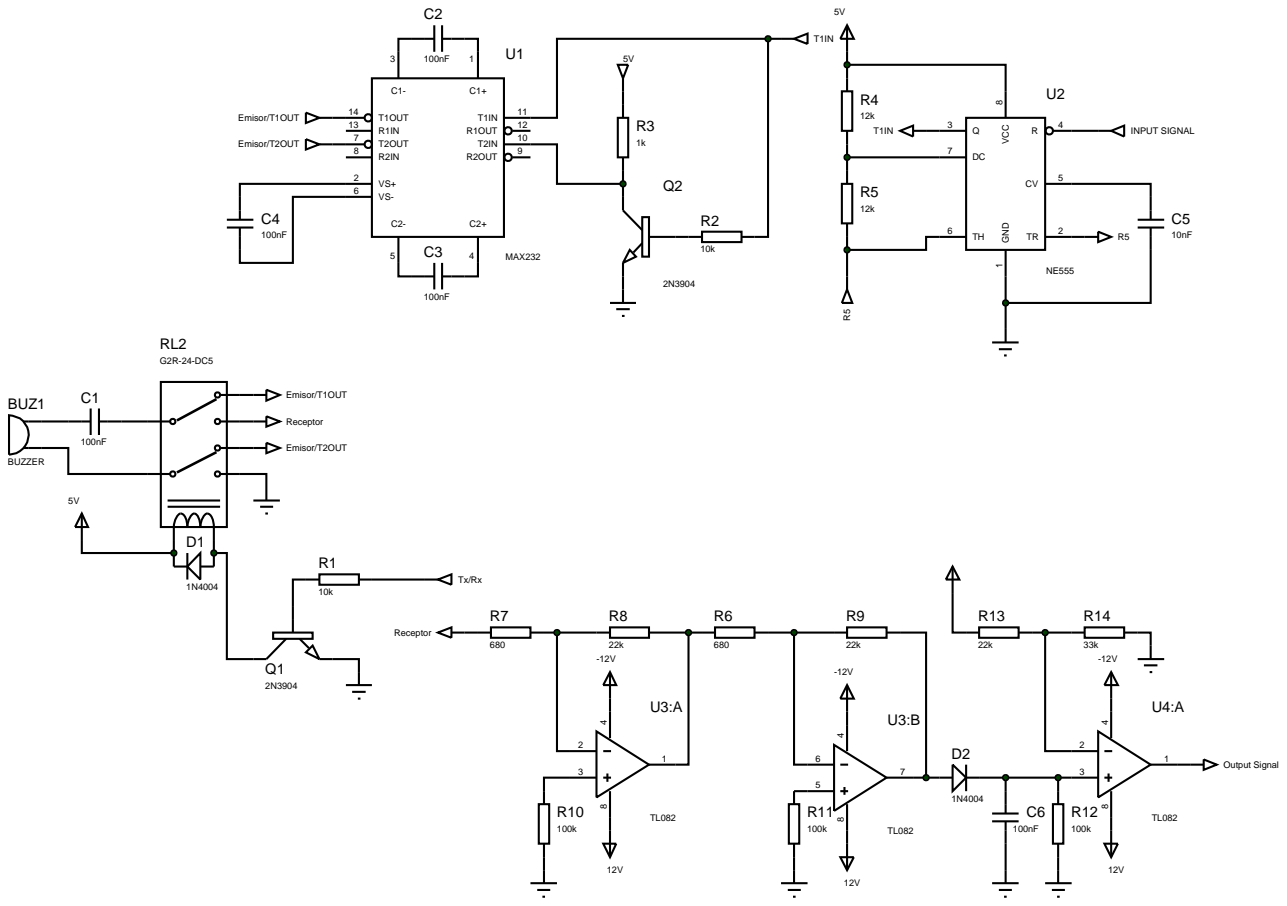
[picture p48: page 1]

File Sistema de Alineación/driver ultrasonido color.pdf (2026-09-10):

U1

C2

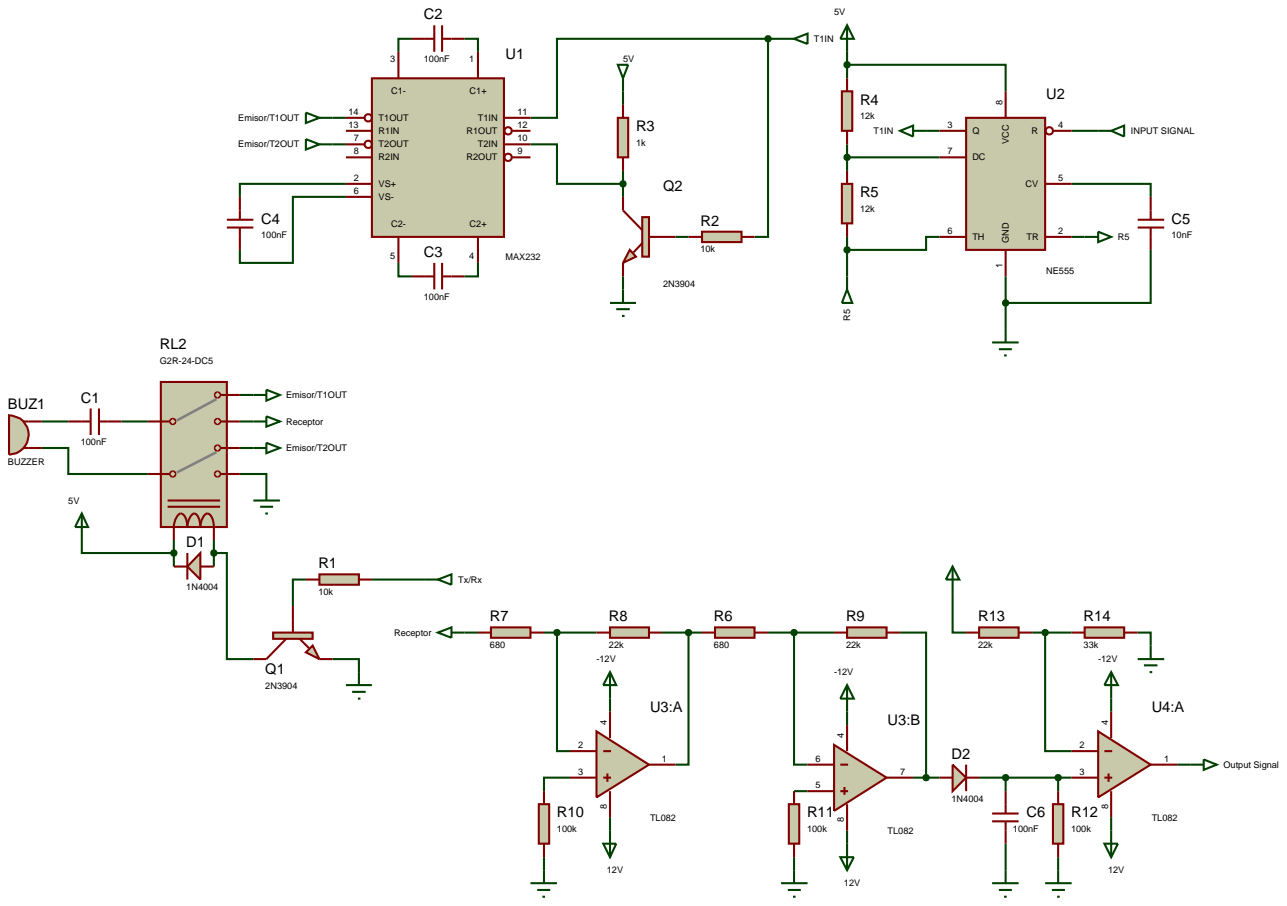
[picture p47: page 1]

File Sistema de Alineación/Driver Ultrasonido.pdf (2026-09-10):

U1

C2
